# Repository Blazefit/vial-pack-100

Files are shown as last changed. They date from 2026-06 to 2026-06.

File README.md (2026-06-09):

# 100× 3 mL Vial Freezer Storage — Compact Stacking Trays

Smallest practical 3D-printable freezer storage for **100 lyophilized 3 mL vials**
(Ø16.51 × 37.74 mm), packed near-cube. Open/vented, PETG/PP, prints on a cheap 220 mm bed.

---

# ▶ CURRENT VERSION — Lidded Modular Tower  → [`current/`](current/)

**Every tray gets its own identical snap lid; the tower stacks `tray → lid → tray → lid …`,
so you can build any height and add layers any time.** Corner gap fixed (clean 45° chamfer),
directed lid drainage, all fits audited.

| | |
|---|---|
| **Footprint** | 106 × 119 mm (near-cube; top-cap lid ~114×127) |
| **Height** | +46.34 mm per layer → **3 layers (105 vials) = 140 mm**, 5 = 233, 10 = 464 |
| **Print per layer** | 1× `tray` + 1× `stacklid` (top layer can use the flush `lid`) |
| **Material** | **PETG or PP — not PLA** (PLA goes brittle at freezer temps) |
| **Verified** | `fit_audit.py` + `checks_lidded.py` all pass; all parts render manifold |

**Download the print files (current):**
- Tray ×N → https://github.com/Blazefit/vial-pack-100/raw/main/current/tray.stl
- Stacklid ×N → https://github.com/Blazefit/vial-pack-100/raw/main/current/stacklid.stl
- Flush top lid ×1 → https://github.com/Blazefit/vial-pack-100/raw/main/current/lid.stl
- Source + audits → [`current/`](current/)

> Print **one tray + one stacklid first** to test the snap + stack fit, tune
> `reg_clr` / `catch_step` / `bore_clear`, then run the rest.

---

# Iteration history → [`iterations/`](iterations/)

Each folder is a complete, self-contained snapshot of that design stage (reconstructed
from git history). Newest last.

| # | Folder | What it was | Why it changed |
|---|---|---|---|
| 1 | [`iterations/1-bundle-cube`](iterations/1-bundle-cube) | Dense honeycomb cube, vials stacked 3-deep in shared bores | Rule added: every vial needs its **own** holder |
| 2 | [`iterations/2-trays-sleeve-v1`](iterations/2-trays-sleeve-v1) | Individual pockets in stacking trays + outer sleeve | First individual-holder design |
| 3 | [`iterations/3-trays-sleeve-v2`](iterations/3-trays-sleeve-v2) | +15 improvements: snap lid, stacking grooves, push-hole, relief holes, corner key, checks | Hardened the tray/sleeve system |
| 4 | [`iterations/4-sleeveless-tower-v3`](iterations/4-sleeveless-tower-v3) | **Dropped the sleeve** — trays interlock directly; thin-wall tube cups | Cut filament ~52% (~1050 g → ~514 g); fixed bottom-layer access |
| 5 | [`iterations/5-lidded-stack-v4`](iterations/5-lidded-stack-v4) | **= CURRENT.** Per-tray lids, modular any-height, directed drainage, corner gap fixed | Modular height + sealed-per-layer + corner fix |

## Design facts (all versions)
- Vials are sealed by their own crimp + septum → the container never needs to seal the
  powder. **Open/vented is correct for a freezer** (no condensation trap; meltwater drains).
- Hexagonal close-packing; ~0.9 L of vials → ~1.0–1.3 L container depending on features.
- All parts print flat, no supports, on a 220 mm bed.

## Note on OpenSCAD part files
Render each part via its `*_part.scad` wrapper. The dispatcher uses a **read-only**
`part_sel` selector — never re-assign `PART`, or OpenSCAD's last-assignment hoisting
silently renders the default part for every wrapper.

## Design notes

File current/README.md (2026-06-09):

# Lidded-stack variant (v6) — modular, inboard keyed registers

A separate, opt-in variant of the [sleeveless tray tower](../README.md). **Every tray
gets its own identical lid** (`stacklid`) and the tower stacks `tray → lid → tray → …`
— **fully modular: stack as many layers as you like, add more any time.**

## v6 — register redesign (fixes a real v5 defect)

A geometry review of the v5 STLs found that the **"lighter frame" trim (rim 3.0→2.5 mm)
made the perimeter register groove (2.8 mm wide) wider than the rim itself**. Mesh
slices proved the cut severed the frame's bottom 3.4 mm: the tray's outer wall floated
1.8 mm above the floor, printed as a full-perimeter overhang over air, and the groove
had no walls left. The stacklid's matching cut left its register tongue standing on a
0.6 mm cantilever lip. Two cups per long side were also gutted by the finger scallops,
and the engraved IDs dipped into the snap-detent recess (chopped glyph bottoms).

v6 fixes all of it at the root:

1. **Inboard keyed registers** — a walled groove cannot live in a ≤3 mm rim, so both
   register interfaces moved inboard into solid material:
   - **A (lid on tray):** tray-top tongue (1.2 × 1.2 mm, inset 1.0 on the rim) seats in
     a walled slot in the lid/stacklid **underside plate** (cap over slot: 2.6 mm, vs
     0.6 mm in v4/v5).
   - **B (tray on stacklid):** stacklid-top tongue (1.2 × 1.0 mm, inset 3.3) seats in a
     walled slot in the tray **floor underside** (0.4 mm cap bridges the 1.8 mm slot —
     trivial bridge; the rim now prints solid from the bed up).
   - **True orientation key:** each tongue has a 45° corner flat and each slot a matching
     corner **block** — a 180°-rotated part hits ~1 mm of solid interference and cannot
     seat (boolean-verified in OpenSCAD).
2. **Finger scallops removed** — vestigial from the v3 solid cup block; against the v5
   open frame they cut through the frame **and through the bore of 4 cups**. Grip is the
   full 42 mm exposed side walls once the layer above is lifted off.
3. **Engraved IDs raised** (`tray_h−3.6 → −2.2`) — clear of the detent recess by 0.5 mm,
   so A–E / 1–7 print whole.
4. **Audit hardening** — `checks_lidded.py` now **parses the live `.scad` and fails on
   param drift** (the v5 bug passed the old checks because they still mirrored v4
   params). New assertions: slot walls exist, caps printable, no perimeter cut below the
   floor, rotation key engaged, drains clear the tongue ring.

5. **Snap-latching stacklids** — bead segments inside each lid's underside slot
   click into a groove on the tray tongue's outer flank (0.2 mm engagement, the
   same class as the proven vial nubs). **Every tray+lid is now a latched unit**
   — vials stay covered even if a lifted layer tips — while the top tongue is
   untouched, so stacking is unchanged. Seating is still interference-free
   (boolean-verified 0 mm³); lifting a seated lid 0.5 mm hits 0.58 mm³ of solid
   interference (the latch provably retains). Peel from a corner to open.

Carried over from v5: skirtless drain-plate stacklid (prints plate-on-bed, support-free),
engraved IDs + label recess, lighter frame (rim 2.5 / floor 1.6), retention nubs
(~0.2 mm) so vials don't fall from a lifted tray.

Footprint **106 × 119 mm**. All parts render manifold; `fit_audit.py` +
`checks_lidded.py` pass; all five mating interfaces boolean-verified collision-free
(and the rotated-tray case verified to **collide**, which is the point).

| Tower (5 layers — stack any number) | Stacklid (drain holes + register tongue) |
|---|---|
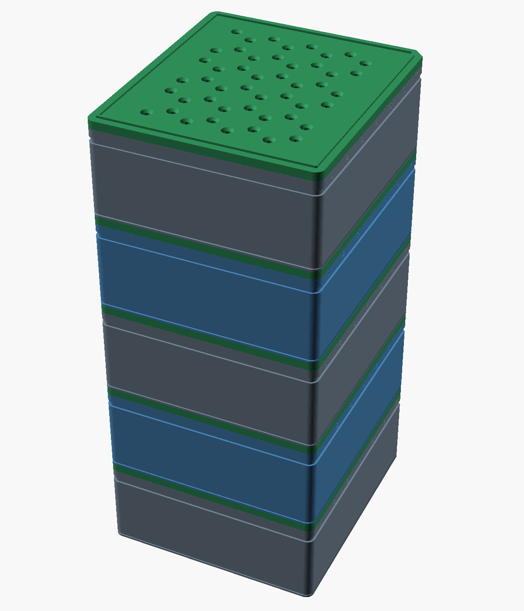
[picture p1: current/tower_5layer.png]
tower
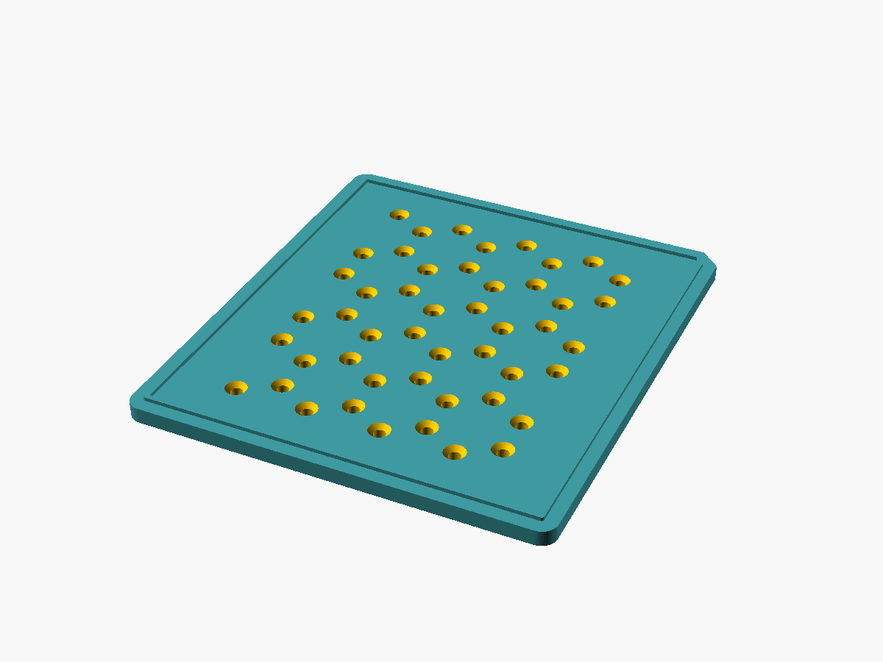
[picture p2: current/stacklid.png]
stacklid
|  |  |

## Stack any height (the modular part)
Every lid is a `stacklid`, so each `(tray + stacklid)` unit is a repeatable module.
`LAYERS` in `vial_trays_lidded.scad` only drives the preview/height math — **the
printed parts don't change**; you just print one more `tray` + one more `stacklid`
for each extra layer.

modular stacking — 1/3/5/10 layers, to scale

| Layers | Vials | Height (extendable) | Height (flush cap) |
|---:|---:|---:|---:|
| 1 | 35 | 47.3 mm | 46.3 mm |
| 2 | 70 | 93.7 mm | 92.7 mm |
| **3** | **105** | **140.0 mm** | **139.0 mm** |
| 5 | 175 | 232.7 mm | 231.7 mm |
| 10 | 350 | 464.4 mm | 463.4 mm |

Footprint stays **106 × 119 mm** at any height. Per-layer pitch is a constant
**46.34 mm** (tray 42.34 + lid plate 4.0); the inter-layer tongues recess into the
slots and add nothing. The exposed top tongue adds just 1.0 mm (vs 3.0 in v5).

### Why the topmost lid used to be different — and isn't anymore
Earlier the top layer used a plain `lid()` (no top tongue) so the very top finished
flush. But a plain lid has nothing for the next tray to seat on, so you **couldn't
extend the stack**. Now every lid is a `stacklid`; the **topmost** one simply leaves
its register tongue **exposed** (a 1.2 mm-wide, 1.0 mm-tall inboard ring). It's
harmless and means you can always stack another module on top. When you've settled on
a final height and want a clean flush top, set `FLUSH_TOP=true` (or just print **one**
`lid.stl`) to cap the very top — but then that cap can't be stacked on.

## Why the per-layer cost is small
The top-cap lid skirt **telescopes down over the tray** (overlap = zero added height),
so each added layer costs only the 4 mm lid plate on top of the tray it caps. Verified
by `checks_lidded.py` and by rendering all three parts manifold in OpenSCAD.

## Directed drainage
The lids carry **48 × Ø3 mm holes** placed on the hex **interstices** (the centroids
between every 3 cups). They clear the vials below by ~1 mm, so meltwater is routed
**between** the vials and never drips onto a crimp/septum. Disable with
`-D lid_drain=false`.

## Fit & geometry verification (v6)
- `fit_audit.py` — every mating interface with real numbers (snap, both registers,
  inter-layer clearance, vial/drain, printability). ALL PASS.
- `checks_lidded.py` — design-rule checks **+ param-drift guard against the live scad**.
- OpenSCAD boolean interference tests: stacklid-on-tray, tray-on-stacklid, lid-on-tray,
  vials-vs-plate-above → all empty (no collision); **rotated tray → 0.99 mm collision**
  (orientation key works).
- Mesh z-slices: tray cross-section is full footprint from z=0 up (v5 was missing its
  entire perimeter below z=3.4).

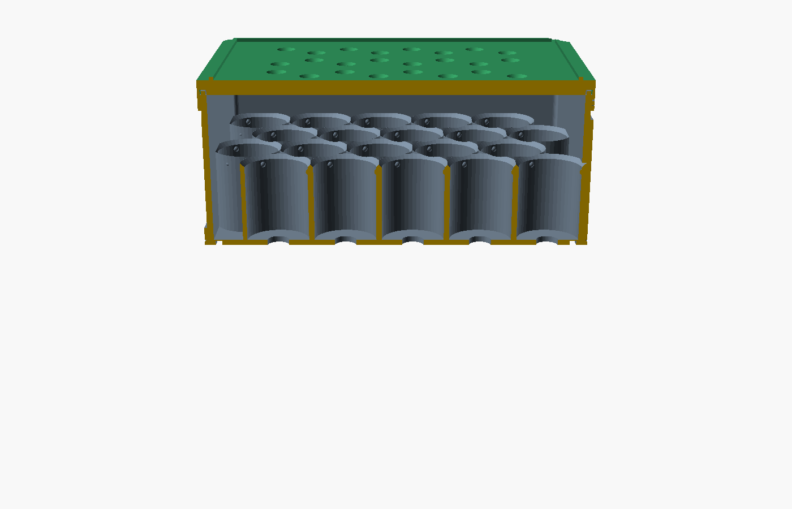
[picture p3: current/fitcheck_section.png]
lid seated on a tray, sectioned — skirt telescopes down over the rim


## Print recipe (modular)
For an **N-layer** tower:

| Part | Qty | File |
|---|---|---|
| tray | **N** | `tray.stl` |
| lid (universal) | **N** | `stacklid.stl` |
| flush top cap | 0 or 1 | `lid.stl` *(optional — only if you want a flush, non-extendable top)* |

So the default 3-layer tower = **3 × tray + 3 × stacklid** (+ optional 1 × `lid`).
PETG (freezer-tough), flat, no supports, 0.4 mm nozzle, 3 perimeters.

## SHRINK toggle (height vs stiffness)
The v6 underside slot is only 1.4 mm deep, so the lid plate is no longer pinned at
4.0 mm by a fragile cap. `SHRINK=true` thins it to **3.0 mm** (cap over slot still
1.6 mm — fine) and shortens the tower by 3 mm per 3 layers. Default `false` keeps the
stiffer 4.0 plate.

> The bigger lever for a shorter tower is a **recessed lid** (drop the plate into the
> 3 mm vial clearance) — not built here yet.

## Render / verify
```bash
python3 checks_lidded.py     # includes the param-drift guard vs the .scad
python3 fit_audit.py
openscad -o stacklid.stl --export-format=binstl lidded_stacklid_part.scad   # universal lid
openscad -o tray.stl     --export-format=binstl lidded_tray_part.scad
openscad -o lid.stl      --export-format=binstl lidded_toplid_part.scad     # optional flush cap
# preview a taller tower: render the assembly with any LAYERS
openscad -o tower.png --render -D LAYERS=5 lidded_assembly_part.scad
```

> ⚠️ Verified in software + manifold renders. Print **one tray + one stacklid** first
> to test the lid snap, the tray-on-lid seat, the rotation key, and the drain spacing,
> then stack the rest.

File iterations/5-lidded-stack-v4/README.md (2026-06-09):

# Lidded-stack variant (v4-lidded) — modular TEST VERSION

A separate, opt-in variant of the [sleeveless tray tower](../README.md). Instead of
the trays interlocking **directly** (tongue→groove, one lid on top), **every tray
gets its own identical lid** (`stacklid`) and the tower stacks
`tray → lid → tray → lid → …`. Each layer is a self-contained, snap-closed,
liftable module — and because every lid is the same, the tower is **fully modular:
stack as many layers as you like and add more any time.**

| Tower (5 layers — stack any number) | Stacklid (drain holes + register tongue) |
|---|---|
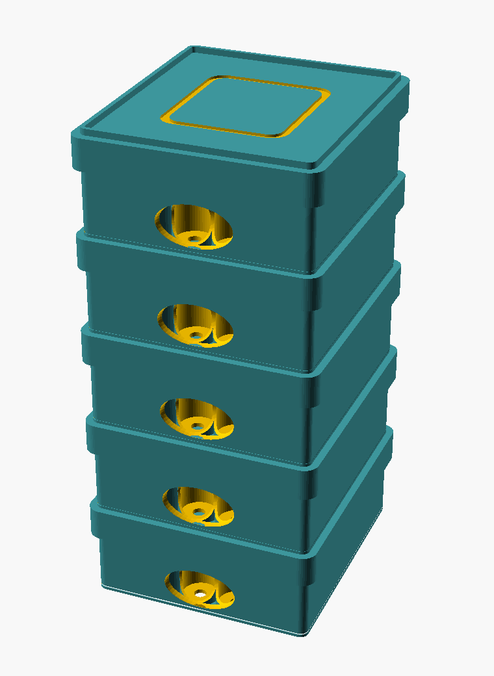
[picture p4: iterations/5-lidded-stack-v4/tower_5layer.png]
tower
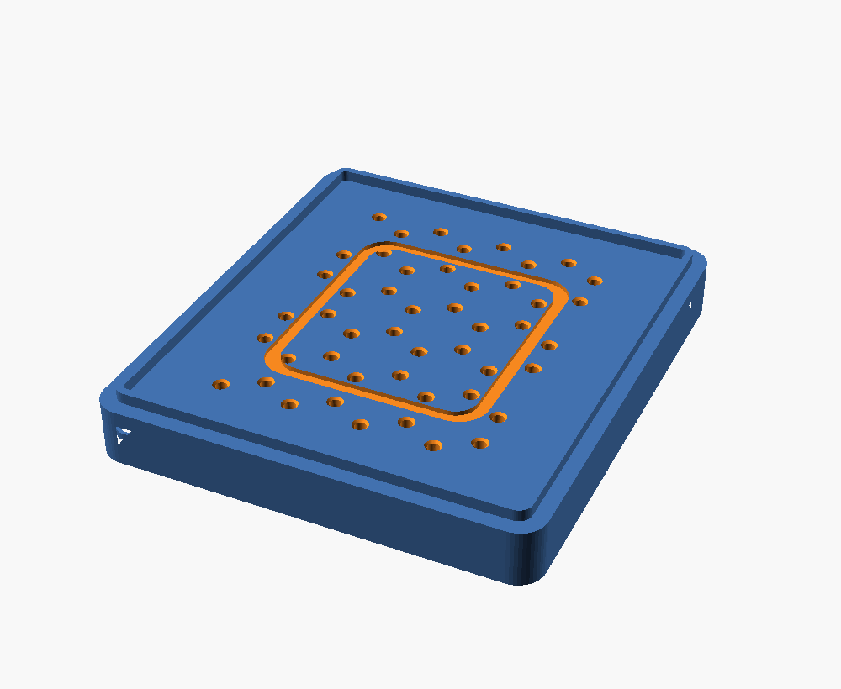
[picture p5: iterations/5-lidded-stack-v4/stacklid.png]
stacklid
|  |  |

| | v3 sleeveless | **v4 lidded (modular)** |
|---|---|---|
| Lids | 1 (top only) | **1 identical `stacklid` per tray** |
| Stacks via | tray-on-tray groove | **lid top plate** (register tongue) |
| Max height | fixed 3-tray tower | **unlimited** — add a layer = +46.74 mm |
| 3-layer envelope | 107 × 120 × **132** mm | 107 × 120 × **143** mm (or **140** flush) |
| Drainage | relief holes drain down | **directed lid perforations** (see below) |

## Stack any height (the modular part)
Every lid is a `stacklid`, so each `(tray + stacklid)` unit is a repeatable module.
`LAYERS` in `vial_trays_lidded.scad` only drives the preview/height math — **the
printed parts don't change**; you just print one more `tray` + one more `stacklid`
for each extra layer.

modular stacking — 1/3/5/10 layers, to scale

| Layers | Vials | Height (extendable) | Height (flush cap) |
|---:|---:|---:|---:|
| 1 | 35 | 49.7 mm | 46.7 mm |
| 2 | 70 | 96.5 mm | 93.5 mm |
| **3** | **105** | **143.2 mm** | **140.2 mm** |
| 5 | 175 | 236.7 mm | 233.7 mm |
| 10 | 350 | 470.4 mm | 467.4 mm |

Footprint stays **107 × 120 mm** at any height. Per-layer pitch is a constant
**46.74 mm** (tray 42.74 + lid plate 4.0); the inter-layer tongues recess into the
grooves and add nothing.

### Why the topmost lid used to be different — and isn't anymore
Earlier the top layer used a plain `lid()` (no top tongue) so the very top finished
flush. But a plain lid has nothing for the next tray to seat on, so you **couldn't
extend the stack**. Now every lid is a `stacklid`; the **topmost** one simply leaves
its register tongue **exposed** (a 2 mm-wide, 3 mm-tall ring — that's the +3 mm vs
the flush column above). It's harmless and means you can always stack another module
on top. When you've settled on a final height and want a clean flush top, set
`FLUSH_TOP=true` (or just print **one** `lid.stl`) to cap the very top — but then
that cap can't be stacked on.

## Why the per-layer cost is small
The lid skirt **telescopes down over the tray** (overlap = zero added height), so
each added layer costs only the 4 mm lid plate on top of the tray it caps. Verified
by `checks_lidded.py` and by rendering all three parts manifold in OpenSCAD.

## Directed drainage
The lids carry **48 × Ø3 mm holes** placed on the hex **interstices** (the centroids
between every 3 cups). They clear the vials below by ~1 mm, so meltwater is routed
**between** the vials and never drips onto a crimp/septum. Disable with
`-D lid_drain=false`.

## What changed vs v3
- `tray()` is the v3 tray with the **+x/+y corner closed**: the old corner-key
  *through-notch* cut a 45° cube wider than the 3 mm rim, slicing the corner
  open. It's now a clean 45° **chamfer** (closed wall, still a one-orientation
  marker). So the lidded tray no longer matches the stock `../tray.stl`.
- New `stacklid()` = the v3 lid + a register tongue on top, so the next tray's
  existing bottom groove seats on it (recessed → no extra pitch). It's the
  **universal** lid — print one per tray.
- `lid()` (no top tongue) is kept only as an **optional flush cap** for the very top.

## Fit & geometry hardening
Validated every mating interface with `fit_audit.py` (snap, stacking seat, inter-
layer clearance, vial/drain, printability) and tightened a few:
- **Corner** — closed (chamfer), matched on tray + lid + tongue for a consistent key.
- **Snap** — detent 3.0 → 2.6 mm (0.6 mm play, not 1.0) for a crisper click; added
  a skirt-mouth lead-in so the lid starts over the rim easily.
- **Drainage** — drain funnel 0.6 → 1.2 mm for better surface-water capture.
- **Lid fit protected** — the lid's outer corners stay **rounded** (its proven
  snap/skirt geometry is untouched); only the tray corner is keyed. The snap
  still engages ~98% of the rim and seats on a flush positive stop.
- All interfaces PASS (`fit_audit.py`); all three parts re-render manifold.

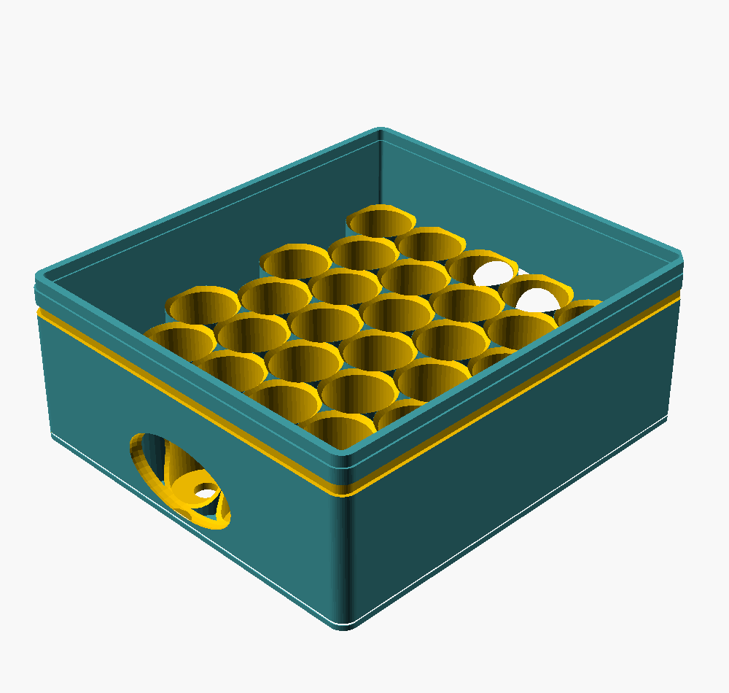
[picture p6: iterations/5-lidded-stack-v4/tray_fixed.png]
tray with the +x/+y corner now closed (45° chamfer)


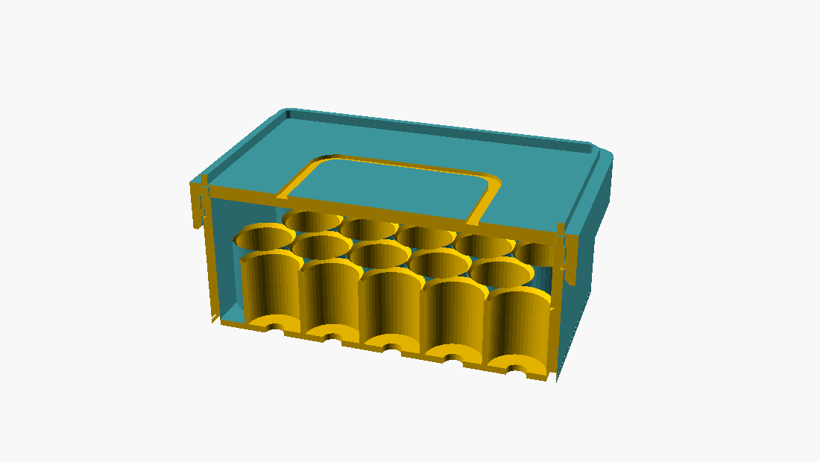
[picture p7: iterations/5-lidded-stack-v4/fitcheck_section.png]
lid seated on a tray, sectioned — skirt telescopes down over the rim


## Print recipe (modular)
For an **N-layer** tower:

| Part | Qty | File |
|---|---|---|
| tray | **N** | `tray.stl` (v3 tray + closed corner — print this one, not stock) |
| lid (universal) | **N** | `stacklid.stl` |
| flush top cap | 0 or 1 | `lid.stl` *(optional — only if you want a flush, non-extendable top)* |

So the default 3-layer tower = **3 × tray + 3 × stacklid** (+ optional 1 × `lid`).
PETG (freezer-tough), flat, no supports, 0.4 mm nozzle, 3 perimeters.

## SHRINK toggle (height vs robustness)
`lid_top_t` is already near its floor: the underside register groove (3.4 mm deep)
leaves only a ~0.6 mm cap, so naively thinning the plate makes **that cap brittle
in the freezer**. Set `SHRINK=true` to shave the plate **and** the register depth
together (`lid_top_t 4→3.5`, `reg_h 3→2.5`); the cap stays ~0.6 mm (not more
fragile) and the per-layer pitch drops by 0.5 mm. Trade-off: the tongue drops to
2.5 mm, so the lidded tray no longer matches the stock `tray.stl` — print this
variant's own `tray.stl`. Default is `false`.

> The real lever for a shorter tower is a **recessed lid** (drop the plate into the
> 3 mm vial clearance), not a thinner plate — not built here yet.

## Render / verify
```bash
python3 checks_lidded.py
openscad -o stacklid.stl --export-format=binstl lidded_stacklid_part.scad   # universal lid
openscad -o tray.stl     --export-format=binstl lidded_tray_part.scad
openscad -o lid.stl      --export-format=binstl lidded_toplid_part.scad     # optional flush cap
# preview a taller tower: render the assembly with any LAYERS
openscad -o tower.png --render -D LAYERS=5 lidded_assembly_part.scad
```

> ⚠️ Verified in software + manifold renders. Print **one tray + one stacklid** first
> to test the lid snap, the tray-on-lid seat, and the drain spacing, then stack the rest.

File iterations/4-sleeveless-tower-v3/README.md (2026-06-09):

# 100× 3 mL Vials — Sleeveless Interlocking Tray Tower (v3)

Open/vented, freezer-friendly, **cheap to print**. Each vial in its own cup; three identical 5×7 hex trays interlock via tongue/groove into a self-stacking tower; a snap lid clips onto the top tray. **No sleeve.**

cutaway

| | |
|---|---|
| **Vial** | Ø16.51 × 37.74 mm (standard 3 mL serum vial) |
| **Tower envelope** | **107 × 120 × 132 mm** (~114×127 incl. lid skirt; near-cube) |
| **Print** | `tray.stl` ×3, `lid.stl` ×1 |
| **Filament** | **~405 cm³ ≈ 514 g PETG** (down 51% from the v2 solid+sleeve design) |
| **Verified** | `checks.py` (17 checks) + both parts render manifold |

## Why no sleeve
The sleeve was a third of the filament *and* the reason the bottom layer was hard to reach. The trays interlock on their own, so:
- **Bottom-layer access** = just lift the stack apart (slip-fit grooves).
- **Open/vented** — no moisture trap; meltwater drains through the pocket relief holes. Your vials are sealed (crimp + septum), so the container never needs to seal the powder.

## Material — print in PETG or PP, NOT PLA
At freezer temps PLA goes brittle (and it's hygroscopic) — the snap lid and tongue/groove could crack. **PETG** (freezer-tough, printable) is the default; **PP** is ideal if your printer handles it.
- All parts print **flat, no supports**, on a cheap 220 mm bed.
- 0.4 mm nozzle, 3 perimeters.

## Features (v1→v3 evolution)
Individual cups (own floor) · **vial height clearance 3 mm** · **tongue/groove interlock** (anti-shift, lift-apart) · **snap lid** onto top tray · pocket lead-in chamfers · **relief/push hole** per cup (poke a vial out, frost drains) · corner key (one orientation) · finger scallops · lid grip recess · **thin-wall tube honeycomb** + **short cups** (open above) for minimal plastic · `checks.py` dimensional verification.

## Files

| File | Purpose |
|---|---|
| `vial_trays.scad` | Parametric source (tray / lid / assembly) |
| `tray.stl` ×3, `lid.stl` ×1 | Print files |
| `checks.py` | 17 dimensional checks |
| `*_part.scad` | Render wrappers |
| `assembly.png` / `cutaway.png` / `tray.png` / `lid.png` | Renders |

## Tuning

```bash
python3 checks.py
openscad -o tray.stl --export-format=binstl tray_part.scad
```

Key params: `bore_clear` (vial fit), `pocket_wall_h` (cup depth), `cup_wall`, `reg_clr` (tray stack fit), `catch_step` (lid snap), `v_clear`.

> Render each part via its `*_part.scad` wrapper. The dispatcher uses a read-only
> `part_sel` selector — never re-assign `PART`, or OpenSCAD's last-assignment hoisting
> silently renders the default part.

> ⚠️ Verified in software. Print **one tray + the lid** first to test the tray-to-tray
> groove fit and the lid snap, tune `reg_clr` / `catch_step` / `bore_clear`, then run the rest.

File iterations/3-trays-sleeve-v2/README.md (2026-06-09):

# 100× 3 mL Vials — Individual-Holder Stacking Trays (v2)

Each vial in its **own pocket on its own floor**. Three identical 5×7 hex trays (35 pockets each, 105 total) stack inside a sleeve with a **snap lid** → near-cube.

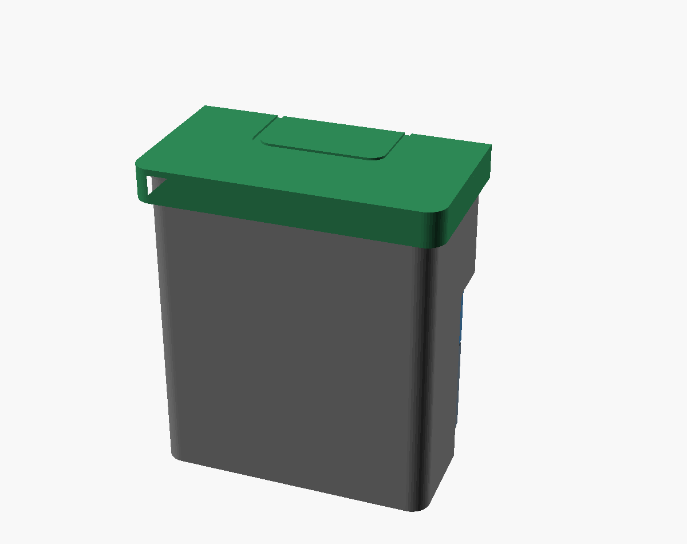
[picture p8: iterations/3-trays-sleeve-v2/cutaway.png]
cutaway


| | |
|---|---|
| **Vial** | Ø16.51 × 37.74 mm (standard 3 mL serum vial) |
| **Assembled envelope** | **118 × 131 × 136 mm** (near-cube, aspect 1.15) |
| **Print** | `tray.stl` ×3, `sleeve.stl` ×1, `lid.stl` ×1 |
| **Verified** | `checks.py` (16 dimensional checks) + all parts render manifold |

## v2 — 15 improvements over v1

1. **Vial height clearance** — explicit 3 mm gap above every vial; stacked trays never crush them
2. **Stacking grooves** — tongue on top rim / groove on bottom rim interlock trays (anti-shift)
3. **Snap lid** — friction skirt + catch lip that clicks under the sleeve's top bead
4. **Bottom-layer removal** — Ø30 mm push-hole in the sleeve base shoves the stack up
5. **Side windows** — short-end openings so any tray (incl. the bottom) is grabbable
6. **Pocket lead-in chamfer** — vials self-center on insertion
7. **Relief/push hole** — Ø6 mm at each pocket bottom: poke a vial out, frost drains
8. **Corner key** — rib in sleeve / notch in tray; trays only seat one orientation
9. **Lead-in chamfer** on the tray bottom edge — drops into the sleeve cleanly
10. **Finger scallops** on tray long sides
11. **Lid grip recess** on top
12. **Tuned clearances** — tongue/groove 0.4 mm, tray-in-sleeve 0.5 mm, lid friction 0.3 mm
13. **Top-edge chamfers** for handling + printability
14. **Dimensional self-check** (`checks.py`) — verifies all 16 fits close
15. **Re-verified** all parts render manifold; corner-key fixed from cosmetic to functional rib

## Print

- **Trays & lid:** flat, pockets/skirt up → no supports. **Sleeve:** open-end up.
- PETG (freezer-friendly), 0.4 mm nozzle, 3 perimeters.
- Print **one tray first** to fit-test with your real vials; tune `bore_clear` if needed.

## Files

| File | Purpose |
|---|---|
| `vial_trays.scad` | Parametric source (tray / sleeve / lid / assembly) |
| `tray.stl` / `sleeve.stl` / `lid.stl` | Print files |
| `checks.py` | Dimensional verification |
| `*_part.scad` | Render wrappers |
| `cutaway.png` / `exploded.png` / `tray.png` | Renders |

## Tuning

```bash
python3 checks.py                                    # verify dims
openscad -o tray.stl --export-format=binstl tray_part.scad
```

Key params at the top of `vial_trays.scad`: `bore_clear`, `v_clear`, `reg_h`/`tongue_t`/`reg_clr` (grooves), `catch_step` (snap), `slide_clr`, `push_hole_d`.

> Render each part via its `*_part.scad` wrapper. The dispatcher uses a read-only
> `part_sel` selector — never re-assign `PART`, or OpenSCAD's last-assignment hoisting
> silently renders the default part for every wrapper.

> ⚠️ Verified in software only. Print one tray + the lid-to-sleeve snap as a fit-test
> before committing to all three trays.

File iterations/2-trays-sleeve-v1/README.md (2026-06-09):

# 100× 3 mL Vials — Individual-Holder Stacking Trays

Redesign of the [near-cube container](../README.md) under one new rule: **every vial gets its own individual pocket** — no vials stacked on top of each other inside a shared tube.

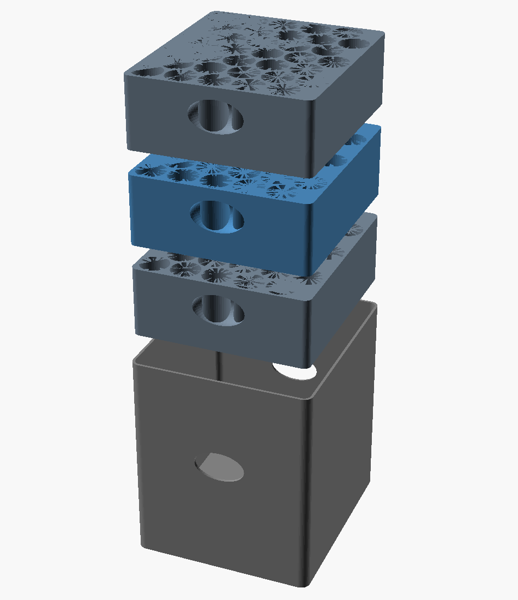
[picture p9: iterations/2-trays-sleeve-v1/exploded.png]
exploded


## Design

- **3 identical trays**, each a 5 × 7 hex grid of **35 individual blind pockets** (105 total, 100 vials + 5 spare).
- Every vial sits in its **own pocket on its own floor** — never bearing another vial.
- Trays drop into a thin **sleeve** that registers them laterally and forms the outer near-cube; optional **lid** keeps freezer frost out.
- **Finger scallops** on the long sides to lift trays (and pinch vials) out.

| | |
|---|---|
| **Vial** | Ø16.51 × 37.74 mm (standard 3 mL serum vial) |
| **Assembled envelope** | **107 × 120 × 126 mm** (near-cube, aspect 1.18) |
| **Parts to print** | `tray.stl` ×3, `sleeve.stl` ×1, `lid.stl` ×1 (optional) |
| **Walls** | 1.5 mm |

## Print

- **Trays & lid:** flat on the plate, pockets up → no supports.
- **Sleeve:** open-end up → no supports.
- PETG (freezer-friendly) or PLA, 0.4 mm nozzle, 3 perimeters.
- Print **one tray first** as a fit-test with your real vials, then run the other two.

## Files

| File | Purpose |
|---|---|
| `vial_trays.scad` | Parametric source (tray / sleeve / lid / assembly) |
| `tray.stl` / `sleeve.stl` / `lid.stl` | Print files |
| `*_part.scad` | Wrappers that select which part to render |
| `assembly.png` / `tray.png` / `exploded.png` | Renders |

## Tuning

Edit the top of `vial_trays.scad`, then per part:

```bash
openscad -o tray.stl --export-format=binstl tray_part.scad
```

- `bore_clear` — vial fit; `cols`/`rows` — grid; `clr` — tray-in-sleeve slide fit.

> Note: render each part via its `*_part.scad` wrapper. The dispatcher uses a read-only
> `part_sel` selector — do **not** re-assign `PART` inside the file, or OpenSCAD's
> last-assignment hoisting silently renders the default part for every wrapper.

> ⚠️ Verified in software (all parts render clean & manifold). Measure your vials and
> print one tray before committing.

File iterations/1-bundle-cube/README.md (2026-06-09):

# 100× 3 mL Vial Freezer Container — Near-Cube Honeycomb

The smallest practical 3D-printable container for **100 lyophilized 3 mL vials**, optimized to be compact in *all three* dimensions (near-cube, not a flat tray).

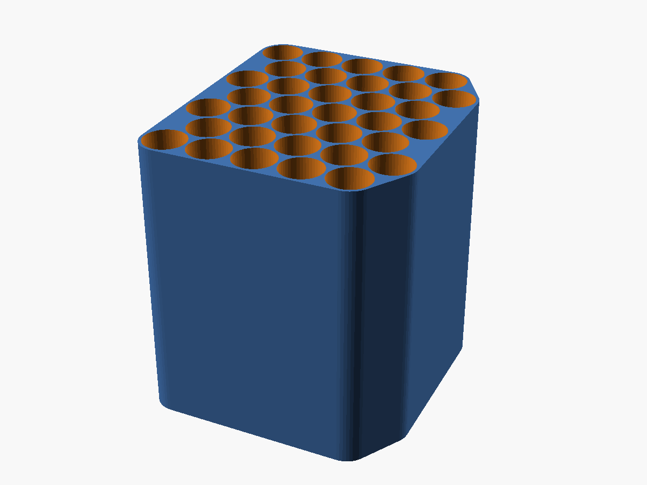
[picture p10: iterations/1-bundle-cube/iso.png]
iso


## Specs

| | |
|---|---|
| **Vial** | Ø16.51 × 37.74 mm (standard 3 mL serum vial) |
| **Capacity** | 105 cells (100 vials + 5 spare) |
| **Layout** | 5 × 7 hexagonal grid × 3 vials deep |
| **Envelope** | **101 × 114 × 115 mm** (aspect 1.13 — near-cube) |
| **Walls** | 1.2 mm (outer + interstitial), 2 mm floor |
| **Packing** | hexagonal close-pack; ~1.3 L bounding for ~0.8 L of glass |

The volume floor for 100 of these vials is ~0.9 L (infinite hex packing); this finite, walled, near-cube lands at ~1.3 L — about as compact as a *usable* hex container gets without going to a 35 cm flat slab.

## Files

| File | Purpose |
|---|---|
| `vial_cube.stl` | **Print this** (binary STL) |
| `vial_cube.scad` | Parametric source — change vial size, grid, walls |
| `cutaway_part.scad` | Renders the cutaway view |
| `pack.py` | Packing optimizer (why 5×7×3 is the near-cube) |
| `iso.png` / `top.png` / `cutaway.png` | Renders |

## Printing

- **Orientation:** print standing up — the bores run vertical (Z), so **no supports** inside the cells.
- **Material:** PETG or PLA (it's a fixture, not wetted). Cold/freezer-safe: PETG preferred.
- **Walls** are 1.2 mm → use a 0.4 mm nozzle, 3 perimeters.
- Vials drop into each cell, stacked 3 deep; load/unload from the open top.

## Tuning

Edit the parameters at the top of `vial_cube.scad` and re-render:

```bash
openscad -o vial_cube.stl --export-format=binstl vial_cube.scad
```

- `bore_clear` — loosen/tighten the vial fit
- `cols` / `rows` / `deep` — change the grid (keep cols·rows·deep ≥ 100)
- `wall` — thinner = smaller but weaker

> ⚠️ Verified in software (renders clean, manifold). Measure your actual vials and print one cell-test before committing to the full block.

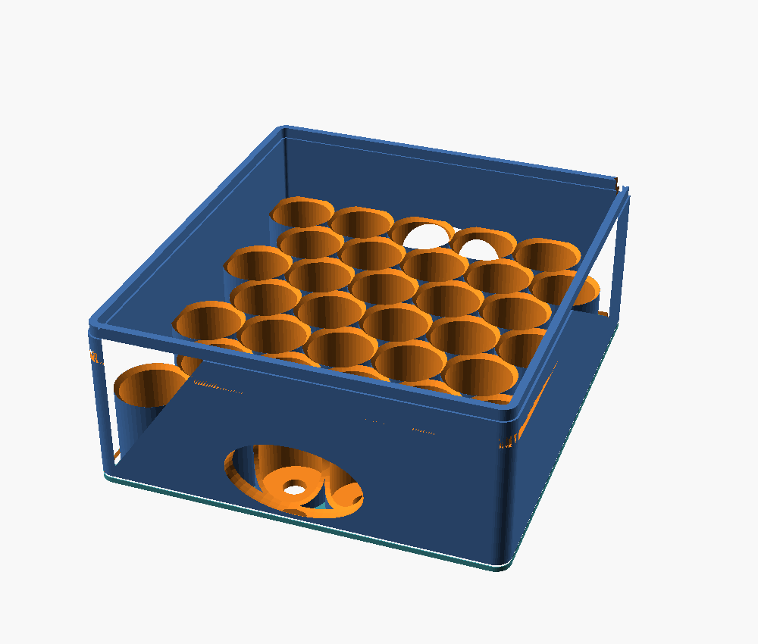
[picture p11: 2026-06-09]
iterations/4-sleeveless-tower-v3/tray.png

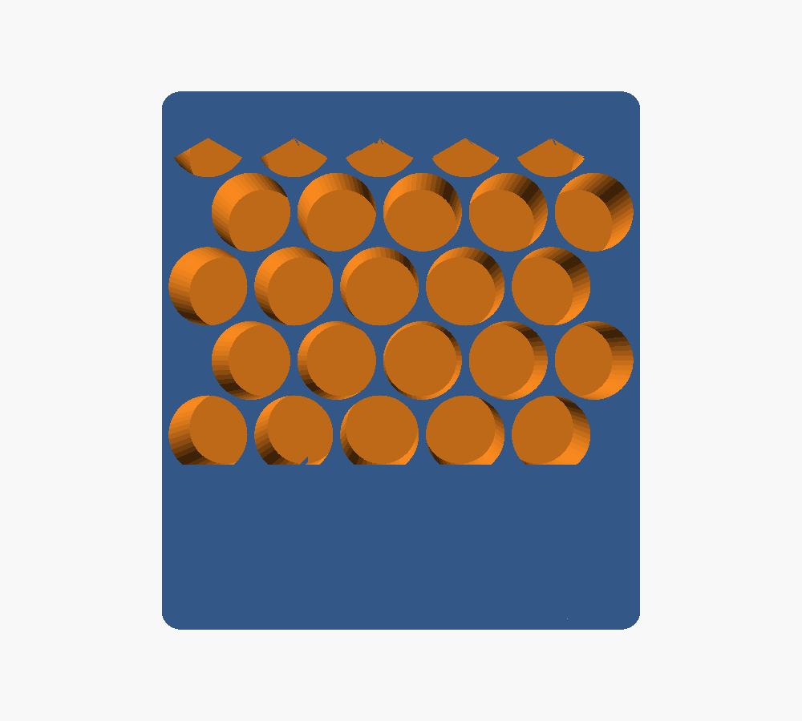
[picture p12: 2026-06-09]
iterations/2-trays-sleeve-v1/tray.png

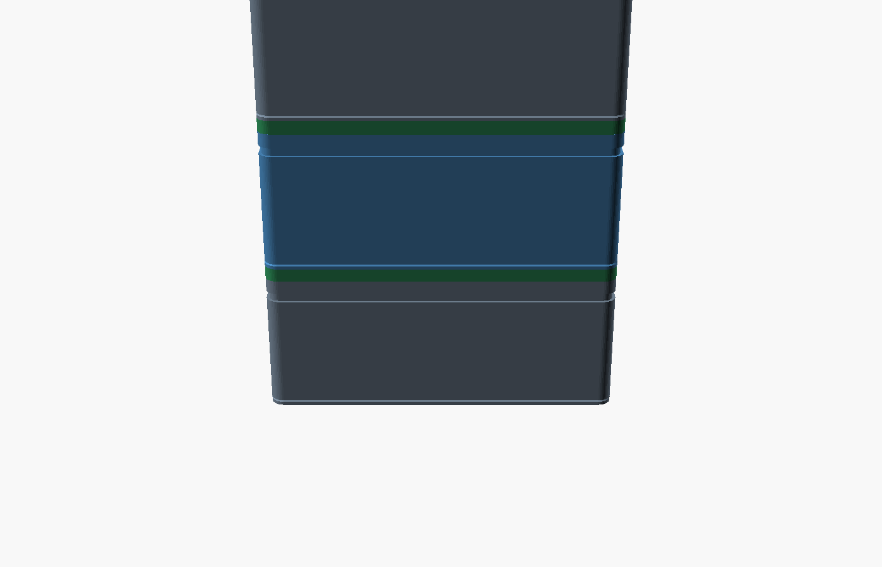
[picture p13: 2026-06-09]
current/cutaway.png

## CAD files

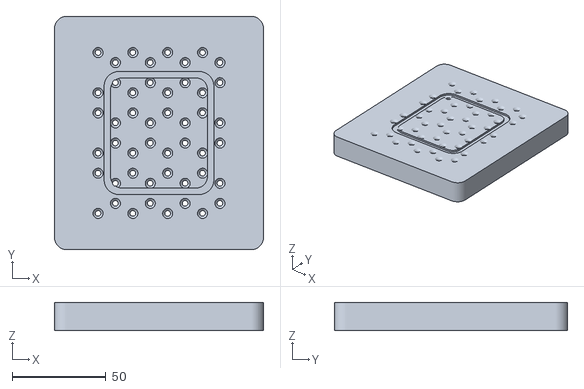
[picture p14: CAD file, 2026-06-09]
current/lid.stl
111.7 x 124.6 x 15.0

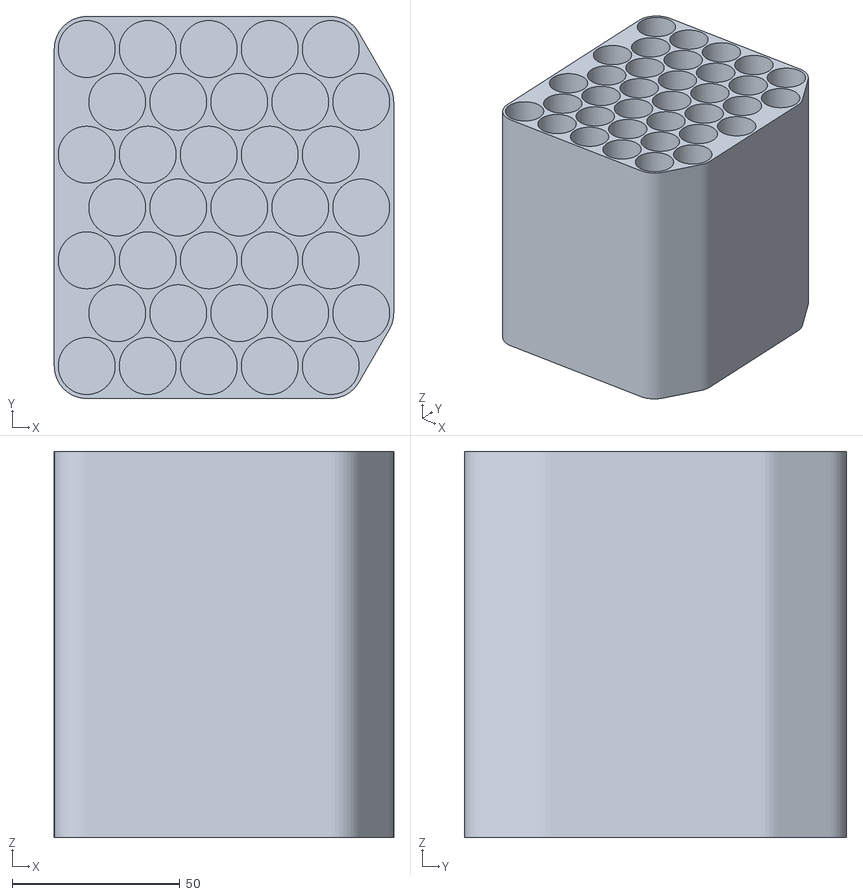
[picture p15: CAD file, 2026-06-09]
iterations/1-bundle-cube/vial_cube.stl
101.4 x 114.0 x 115.2

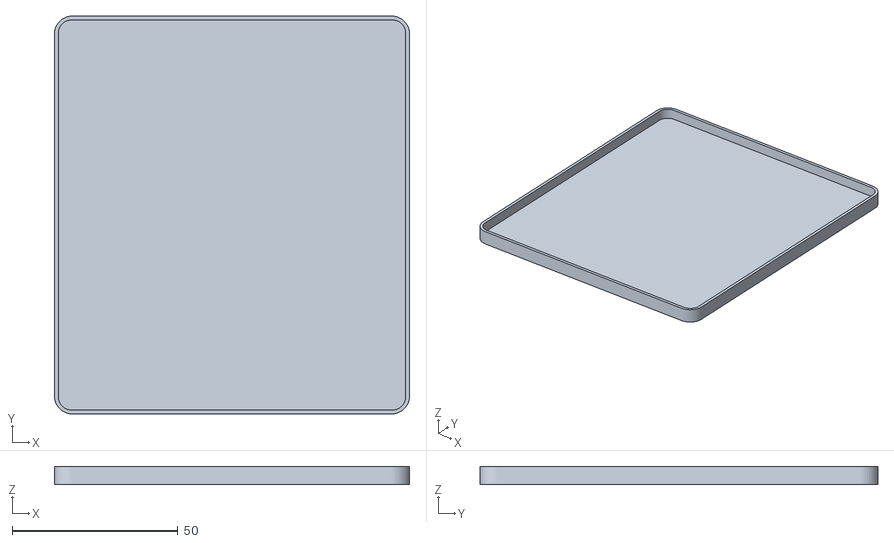
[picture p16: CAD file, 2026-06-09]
iterations/2-trays-sleeve-v1/lid.stl
107.3 x 120.2 x 5.50

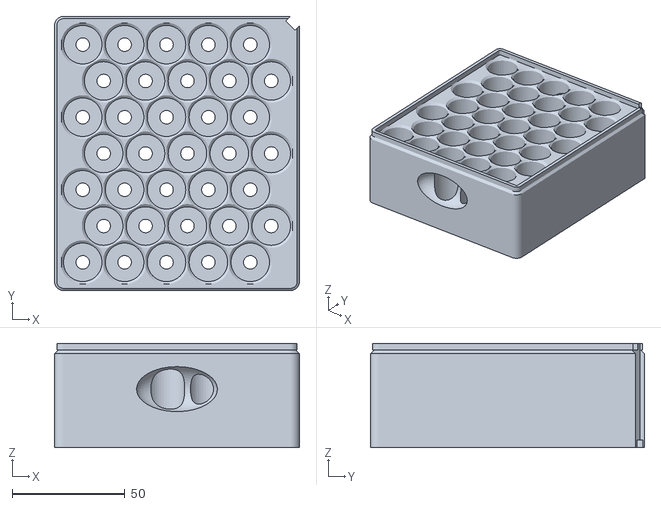
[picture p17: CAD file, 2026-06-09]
iterations/3-trays-sleeve-v2/tray.stl
108.9 x 121.8 x 46.2

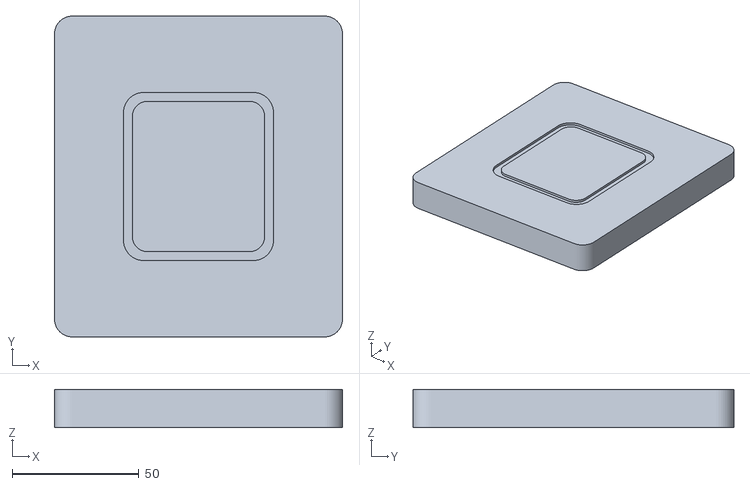
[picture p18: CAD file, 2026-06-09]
iterations/4-sleeveless-tower-v3/lid.stl
113.7 x 126.6 x 15.0

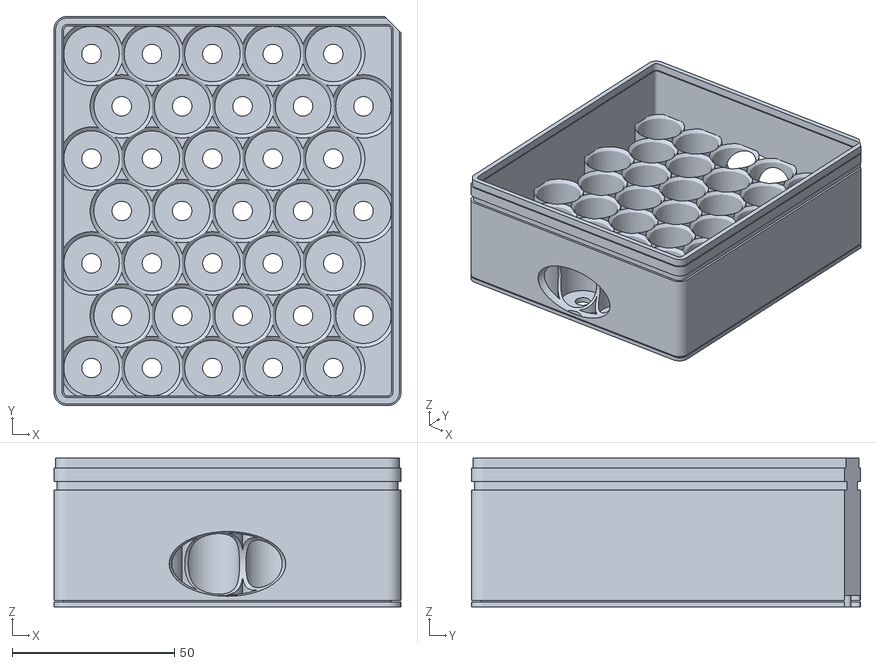
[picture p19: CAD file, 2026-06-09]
iterations/5-lidded-stack-v4/tray.stl
106.9 x 119.8 x 45.7

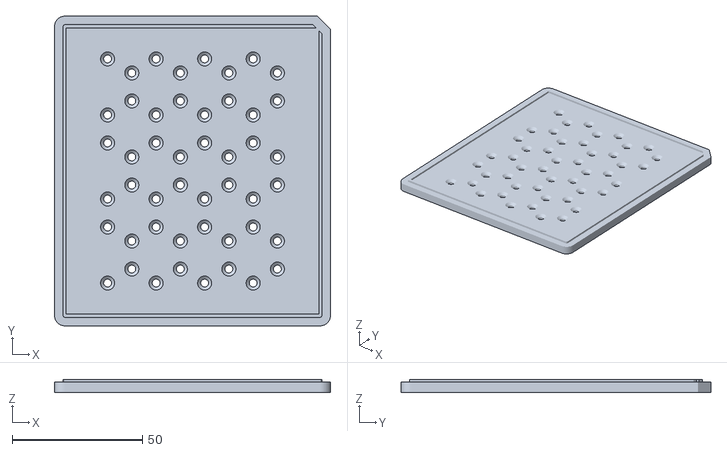
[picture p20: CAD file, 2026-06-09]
current/stacklid.stl
105.9 x 118.8 x 5.00

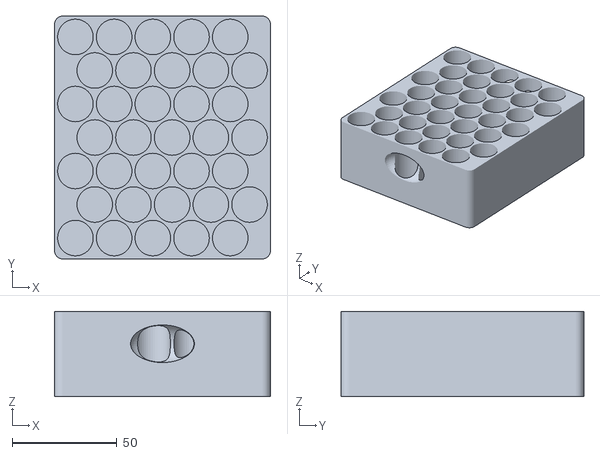
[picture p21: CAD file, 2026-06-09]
iterations/2-trays-sleeve-v1/tray.stl
103.3 x 116.2 x 40.7

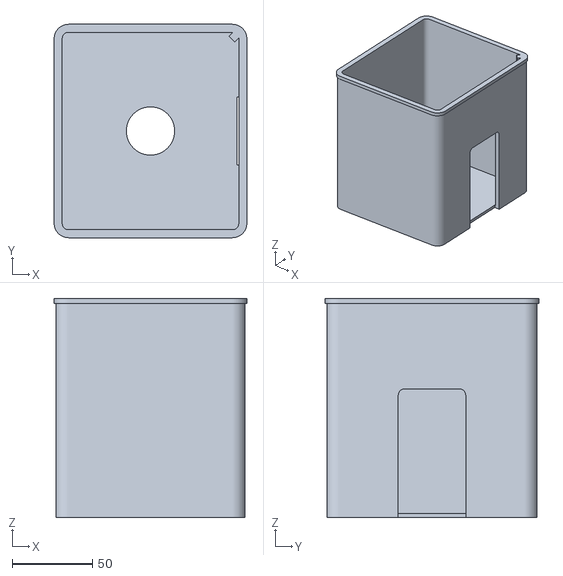
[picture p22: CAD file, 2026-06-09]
iterations/3-trays-sleeve-v2/sleeve.stl
119.9 x 132.8 x 136.2

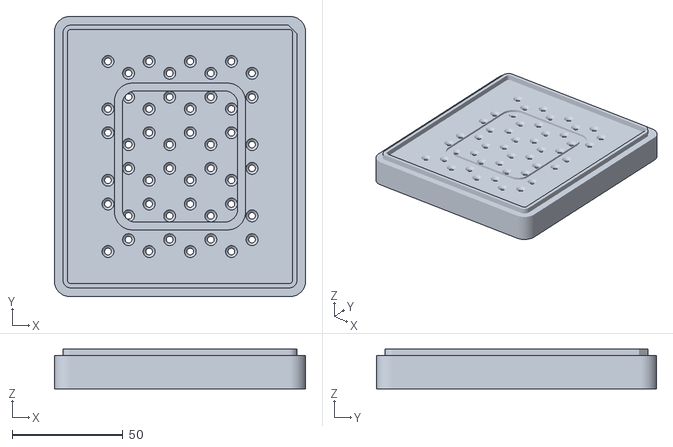
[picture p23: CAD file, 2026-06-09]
iterations/5-lidded-stack-v4/stacklid.stl
113.7 x 126.6 x 18.0

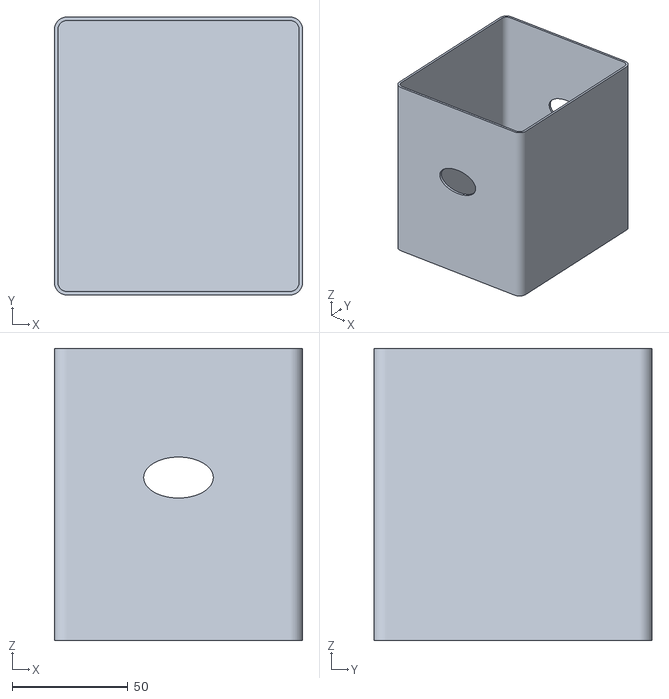
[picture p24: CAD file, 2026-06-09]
iterations/2-trays-sleeve-v1/sleeve.stl
107.3 x 120.2 x 126.2

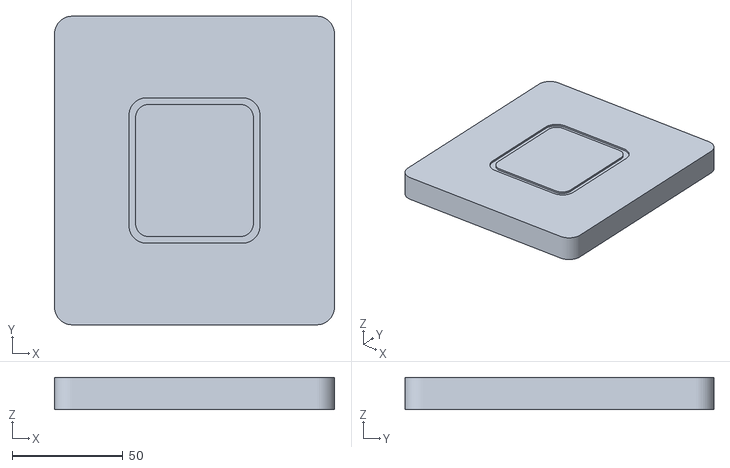
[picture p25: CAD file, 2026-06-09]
iterations/3-trays-sleeve-v2/lid.stl
126.5 x 139.4 x 14.5

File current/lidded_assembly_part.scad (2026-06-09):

PART="assembly";
include <vial_trays_lidded.scad>;

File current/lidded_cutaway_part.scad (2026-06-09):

PART="none";
include <vial_trays_lidded.scad>;
// half-section of the modular tower: LAYERS trays, a stacklid on each, vials in
// their cups. Every layer is identical -> stack as many as you like.
difference() {
    union() {
        for (i=[0:LAYERS-1]) {
            translate([0,0,i*stack_pitch]) color(i%2?"steelblue":"slategray") tray();
            translate([0,0,i*stack_pitch + tray_h]) color("seagreen")
                { if (FLUSH_TOP && i==LAYERS-1) lid(); else stacklid(); }
            for (p=positions())
                translate([p[0],p[1], i*stack_pitch + floor_t]) color("khaki")
                    cylinder(d=vial_d, h=vial_h);
        }
    }
    translate([-300,0,-60]) cube([600,400,600]);   // cut away the +y half
}

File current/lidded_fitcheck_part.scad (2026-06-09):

PART="none";
include <vial_trays_lidded.scad>;
// Lid (stacklid) snapped onto a tray, then sectioned at y=0 so you can SEE the
// fit: skirt telescoped over the tray wall, snap bead sitting in the tray's
// detent, and the lid plate resting flat on the rim. Render with --render.
difference() {
    union() {
        color("slategray") tray();
        translate([0,0,tray_h]) color("seagreen") stacklid();   // seats: plate bottom on rim top
    }
    translate([-300,-400,-80]) cube([600,400,600]);   // cut away -y half -> y=0 section faces the front camera
}

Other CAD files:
iterations/4-sleeveless-tower-v3/tray.stl
iterations/5-lidded-stack-v4/lid.stl
current/lidded_stacklid_part.scad
current/lidded_toplid_part.scad
current/lidded_tray_part.scad
current/vial_trays_lidded.scad
iterations/1-bundle-cube/cutaway_part.scad
iterations/1-bundle-cube/vial_cube.scad
iterations/2-trays-sleeve-v1/assembly_part.scad
iterations/2-trays-sleeve-v1/exploded_part.scad
iterations/2-trays-sleeve-v1/lid_part.scad
iterations/2-trays-sleeve-v1/sleeve_part.scad
iterations/2-trays-sleeve-v1/tray_part.scad
iterations/2-trays-sleeve-v1/vial_trays.scad
iterations/3-trays-sleeve-v2/assembly_part.scad
iterations/3-trays-sleeve-v2/cutaway_part.scad
iterations/3-trays-sleeve-v2/exploded_part.scad
iterations/3-trays-sleeve-v2/lid_part.scad
iterations/3-trays-sleeve-v2/sleeve_part.scad
iterations/3-trays-sleeve-v2/tray_part.scad
iterations/3-trays-sleeve-v2/vial_trays.scad
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

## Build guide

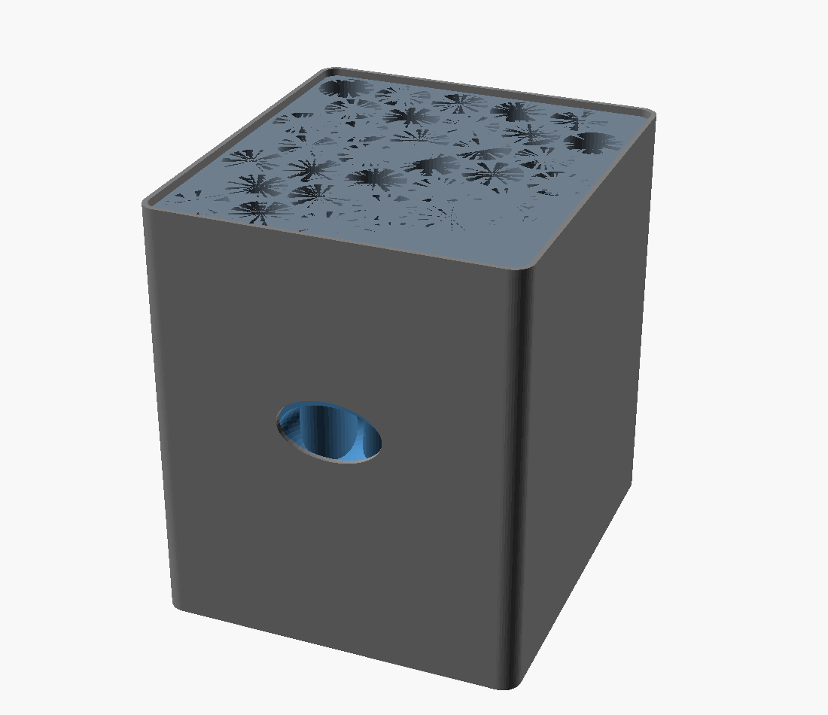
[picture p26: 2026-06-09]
iterations/2-trays-sleeve-v1/assembly.png

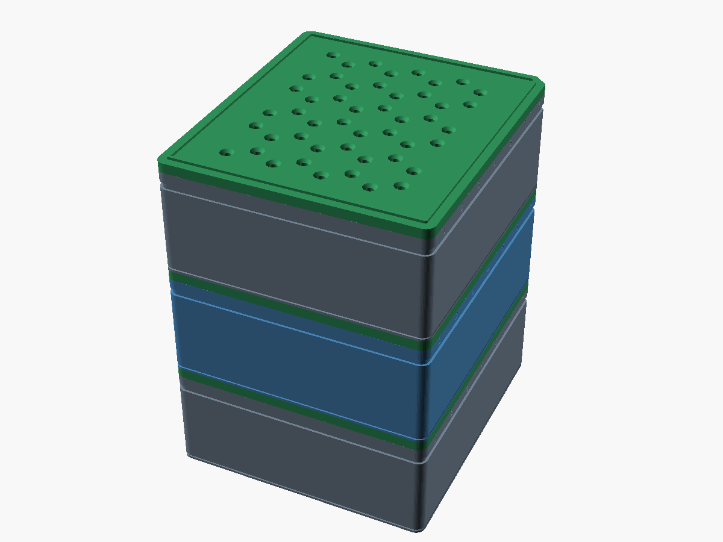
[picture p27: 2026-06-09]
current/assembly_lidded.png

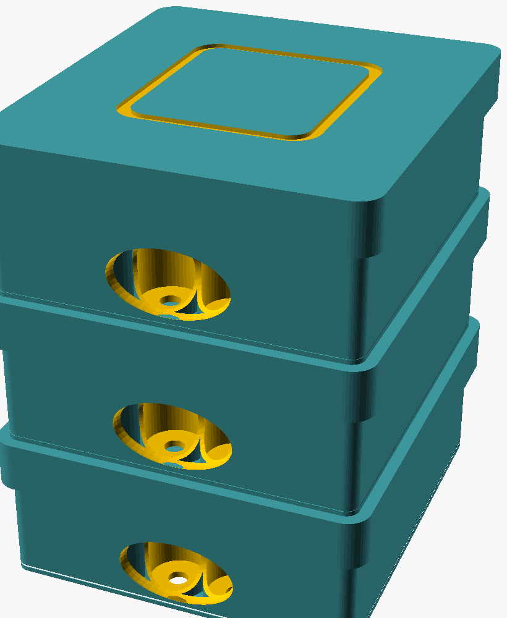
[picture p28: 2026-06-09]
iterations/5-lidded-stack-v4/assembly_lidded.png

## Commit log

2026-06-09 100x 3mL vial near-cube honeycomb freezer container
    Smallest practical printable container for 100 lyophilized 3mL vials:
    5x7 hex grid x 3 deep, 101x114x115mm near-cube. Parametric OpenSCAD +
    binary STL + packing optimizer + renders.
    [cutaway_part.scad, vial_cube.scad, vial_cube.stl]
2026-06-09 Add individual-holder stacking-tray design
    New rule: every vial in its own pocket (no vials stacked in a shared
    tube). 3 identical 35-pocket hex trays + sleeve + lid; assembled
    107x120x126mm near-cube. Parametric SCAD, STLs, renders.
    [assembly_part.scad, exploded_part.scad, lid.stl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]
2026-06-09 Tray system v2: snap lid, stacking grooves, bottom-layer removal, +15 improvements
    - vial height clearance (3mm), tongue/groove tray interlock
    - snap-fit lid (friction skirt + catch lip)
    - sleeve push-hole + side windows for bottom-layer removal
    - pocket lead-in chamfer + relief/push hole, corner key (functional rib)
    - checks.py: 16 dimensional checks all pass; all parts render manifold
    - assembled 118x131x136mm near-cube
    [cutaway_part.scad, exploded_part.scad, lid.stl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]
2026-06-09 v3: sleeveless interlocking tray tower — half the filament
    - drop the sleeve: trays interlock via tongue/groove, lid snaps to top tray
    - thin-wall tube honeycomb + short cups (open above) -> ~half plastic
    - bottom-layer access = lift stack apart; open/vented for freezer
    - material note: PETG/PP not PLA (cold brittleness)
    - full set ~405 cm3 / ~514 g (was ~1050 g); checks.py 17/17 pass; manifold
    [cutaway_part.scad, exploded_part.scad, lid.stl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]
2026-06-09 feat(trays): add lidded-stack variant with directed lid drainage
    Separate v4-lidded TEST version: every tray gets its own lid and the tower
    stacks lid-to-lid (tray -> lid -> tray -> lid) instead of tray-on-tray.
    Reuses the stock tray() (SHRINK=false); the only new geometry is a register
    tongue on the lid top so the next tray's existing bottom groove seats on it.
    - +8 mm vs v3 (132 -> 140 mm); footprint unchanged (skirts telescope over trays).
    - Directed drainage: 48x O3 mm holes on the hex interstices, clearing the vials
    below by ~1 mm so meltwater routes between vials, never onto a crimp/septum.
    - SHRINK toggle trims plate + register depth together (-> 138.7 mm) without
    thinning the re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
    [lid.stl, lidded_assembly_part.scad, lidded_cutaway_part.scad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]
2026-06-09 feat(trays/lidded): uniform lids — stack to any height
    Every tray now gets an identical `stacklid`; the top is no longer a special
    plain lid, so the tower is fully modular — stack any number of layers and add
    more any time. New LAYERS + FLUSH_TOP params drive only the assembly/height
    preview; the printed parts are unchanged (STLs byte-identical).
    - Topmost stacklid leaves its register tongue exposed (+3 mm) so you can always
    extend; FLUSH_TOP=true (or print one lid.stl) caps it flush when done.
    - Per-layer pitch constant 46.74 mm; footprint 107x120 at any height.
    - checks_lidded.py prints a height-vs-layers table; all checks PASS.
    - All 3 parts re-render manifold, byte-identical to th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
    [lidded_cutaway_part.scad, vial_trays_lidded.scad]
2026-06-09 fix(trays/lidded): close the open +x/+y corner + harden fits
    The tray's corner-key was a through-notch (45 deg cube wider than the 3 mm rim)
    that sliced the corner open. Replaced with a clean 45 deg chamfer (closed wall,
    still a one-orientation marker).
    Fit pass (fit_audit.py mirrors every interface):
    - snap: detent 3.0->2.6 mm (0.6 mm play, crisper); skirt-mouth lead-in for easy seat
    - drainage: drain funnel 0.6->1.2 mm for better surface-water capture
    - tongue: corner chamfered to match the tray
    Lid fit deliberately protected: the lid's outer corners stay ROUNDED (proven
    snap/skirt geometry untouched) — only the tray corner is keyed. Snap still
    engages ~98% of the rim with a flush posi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
    [lid.stl, lidded_fitcheck_part.scad, stacklid.stl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]
2026-06-09 Reorganize repo: current version up front + iterations split out
    - current/ = lidded modular tower (v4, the newest/most complete design)
    - iterations/1..5 = each design stage as a self-contained snapshot
    (reconstructed from git history; nothing lost)
    - top-level README leads with the current version + print links, then
    an iteration index explaining why each stage changed
    - removed scattered root files (now under iterations/1-bundle-cube and /4)
    [assembly_part.scad, cutaway_part.scad, exploded_part.scad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]
2026-06-09 chore: remove stray root cutaway_part.scad (clean root)
    [cutaway_part.scad]
2026-06-09 current v5: skirtless stacklid + engraved IDs + lighter frame + retention nubs
    Design-review pass (4 changes, none increase size):
    1. stacklid skirtless flat drain-plate -> prints support-free, ~68->47 cm3,
    no skirt overhang; top cap lid keeps the snap
    2. engraved A-E / 1-7 IDs + write-on label recess (address all 100 vials)
    3. frame trimmed (rim 3.0->2.5, floor 2.0->1.6): tray 112->99 cm3, ~1mm smaller/side
    4. retention nubs at cup mouths (~0.2mm) so vials don't fall from a lifted tray
    All parts render manifold; fit_audit + checks pass.
    [lid.stl, stacklid.stl, vial_trays_lidded.scad]
2026-06-09 Fix v5: manifold tray + sync audits/README to trimmed dimensions
    The published current/tray.stl was a preview export — 69 interpenetrating
    shells (watertight=False), despite the README claiming all parts manifold.
    Re-rendered via CGAL into a clean single watertight solid (99.4 cm3); stacklid
    and lid were already manifold.
    The v5 frame trim (rim 3.0->2.5, floor 2.0->1.6) was applied in the .scad but
    not propagated, so:
    - fit_audit.py / checks_lidded.py hardcoded the old 3.0/2.0 -> they audited the
    wrong design. Synced to 2.5/1.6; both still PASS, now on the real geometry.
    - README height/pitch/footprint were stale (46.74mm / 143.2mm / 107x120).
    Updated to the audit's authoritative numb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
2026-06-09 v6: inboard keyed registers — fixes v5 rim-severing defect, all parts manifold
    Register redesign: v5's perimeter groove (2.8 mm) was wider than the trimmed
    2.5 mm rim and severed the frame's bottom 3.4 mm. v6 moves both register
    interfaces inboard into solid material with 45-deg corner keys (a 180-deg
    rotated part cannot seat), removes the vestigial finger scallops that gutted
    4 cup bores, and raises the engraved IDs clear of the snap detent.
    Review-loop fixes on top of the base v6 work:
    - Tray-top tongue fused to the rim (was a floating 0.61 cm3 body the Manifold
    backend silently glued; CGAL exposed it)
    - Snap detent recess rebuilt as one cut solid with overlapped joints (the old
    sta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
    [lid.stl, stacklid.stl, vial_trays_lidded.scad]
2026-06-09 snap-latching stacklids: every layer lid clicks closed, stacking unchanged
    Bead segments (4x 24 mm, staircase lead on the insertion/print side, square
    retention face) on the underside-slot outer wall of both lids click into a
    0.35 mm groove around the tray tongue's outer flank. Each tray+lid becomes a
    latched unit; interface B (stacklid-top tongue -> next tray) is untouched, so
    the tower stacks exactly as before. The top cap lid gets the tongue latch on
    top of its existing skirt snap.
    Boolean-verified: seated stacklid/lid = 0 mm3 interference (drops on clean);
    seated stacklid lifted 0.5 mm = 0.58 mm3 solid clash (latch retains); rotated
    180 deg = 4.48 mm3 (corner key still blocks). All thre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
    [lid.stl, stacklid.stl, vial_trays_lidded.scad]
2026-06-10 CI: manifold audit — fail on any non-watertight STL
    trimesh-based check over every committed *.stl; .manifoldignore
    holds intentional non-printables (the superseded v3 preview tray).
    Actions pinned to commit SHAs.
